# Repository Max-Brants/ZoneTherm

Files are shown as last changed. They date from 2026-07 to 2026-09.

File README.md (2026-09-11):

<picture>
  <source media="(prefers-color-scheme: dark)" srcset="brand/zonetherm-logo-dark.svg">
  ZoneTherm
</picture>

# ZoneTherm

**A 7-zone OpenTherm heating/cooling controller.** ESP32-S3 firmware, KiCad
hardware, and a Svelte web UI for a house where every room has its own
OpenTherm room thermostat but the plant has a single manifold of zone valves.

Version 1.0.0.

---

## The idea

A normal OpenTherm setup is one thermostat talking to one boiler. ZoneTherm sits
in the middle of seven of those conversations at once:

```
 Room thermostat 1  ──OpenTherm──┐
 Room thermostat 2  ──OpenTherm──┤
        ...                      ├──►  ZoneTherm  ──I²C──►  MCP23017  ──►  7 zone valves
 Room thermostat 7  ──OpenTherm──┘        │
                                          ├──► Ethernet / WiFi ──► MQTT ──► Home Assistant
                                          └──► Web UI + REST API
```

To each thermostat, ZoneTherm **pretends to be a boiler**. It answers every
OpenTherm request the thermostat makes, so the thermostat behaves exactly as it
would on a real appliance — it shows a flame, it runs its own schedule, it lets
you turn the dial. While answering, ZoneTherm captures the two numbers that
matter: the room temperature the thermostat measured, and the setpoint it is
asking for.

It then makes the only decision that is actually its own: for each thermostat,
should heat be flowing? That is a bang-bang comparison with a symmetric
hysteresis band, and it lives in exactly one function
([`ClimateLogic::valveWanted`](Code/src/domain/ClimateLogic.h)).

Each thermostat drives a **valve set** — one valve, or several. A room with
three underfloor loops has three actuators and one thermostat, and they open
and close together in a single I²C write.
[`ValvePlan::solve`](Code/src/domain/ValvePlan.h) turns the seven per-room
answers into the one byte the expander wants. A valve belongs to at most one
thermostat, which the web UI enforces by greying out valves already taken and
the API enforces by rejecting the save.

One **season** — heating or cooling — applies to the whole plant, because
there is one set of pipes. Individual zones can be disabled, but they cannot
disagree about which direction the water is going.

Setpoints can also be pushed the other way. A setpoint sent from Home Assistant
or the web UI is written back to the room thermostat over OpenTherm's
`TrOverride` mechanism, so the wall unit shows the new target too.

### Things worth knowing before you build one

- ZoneTherm **is not a gateway.** There is no upstream boiler connection in the
  main firmware. It terminates all seven OpenTherm links itself and drives
  valves; your boiler is expected to be commanded by something else (a valve
  end-switch loop, or its own thermostat input).
- A zone whose thermostat has never reported a room temperature keeps its valves
  **closed**, as does a disabled zone. There is no fail-open.
- The same goes for the two ways a valve set can be misconfigured: a thermostat
  with **no valves** keeps tracking its band and reporting demand but opens
  nothing, and a valve **claimed by nobody** never opens. Both are flagged on
  the config page and logged at boot rather than silently guessed at.
- Upgrading from a pre-valve-set firmware leaves the wiring alone: every
  thermostat comes up owning the one valve on its own channel, exactly as
  before.
- `boilerTemp`, `flameOn`, `fault` and friends exist in the zone state and are
  parsed off the wire, but only `modulation` is currently exported as a Home
  Assistant sensor.

---

## Repository layout

| Path | What it is |
|---|---|
| [Code/](Code/) | ESP32-S3 firmware (ESP-IDF via PlatformIO). See [Code/README.md](Code/README.md) for the architecture write-up. |
| [Code/webui/](Code/webui/) | Svelte 5 + Vite + TypeScript single-page app, built into `Code/data/` and flashed as a LittleFS image. |
| [pcb/](pcb/) | KiCad 8 project `ZoneTherm.kicad_pro` — seven OpenTherm slave interfaces, W5500 Ethernet, MCP23017 valve bank. Fabrication outputs in `GERBER/`, `production/`, `jlcpcb/`. |
| [enclosure/](enclosure/) | Three-part printed case, generated from the KiCad board by a script rather than measured off it. See [enclosure/README.md](enclosure/README.md) — **read the mains section before printing one**. |
| [.github/workflows/](.github/workflows/) | Release workflow that builds and publishes the OTA assets. |

---

## Hardware

**Board:** ESP32-S3-DevKitC-1 (16 MB flash, no PSRAM required).

**Pinout** — from [`Code/src/app/Pins.h`](Code/src/app/Pins.h), matching the
`Thermos_In_X` / `Thermos_Out_X` nets on the schematic:

| Zone | In (GPIO) | Out (GPIO) |
|---|---|---|
| 1 | 2 | 1 |
| 2 | 42 | 41 |
| 3 | 40 | 39 |
| 4 | 48 | 47 |
| 5 | 20 | 19 |
| 6 | 18 | 17 |
| 7 | 16 | 15 |

I²C to the MCP23017 valve expander: `SDA = 4`, `SCL = 5`.
Ethernet is a W5500 on SPI — see U3 on `ZoneTherm.kicad_pcb`.

**Flash layout** ([`Code/partitions.csv`](Code/partitions.csv)) — dual OTA app
slots plus a large filesystem, which is what makes both firmware *and* web UI
updatable over the air:

| Partition | Offset | Size |
|---|---|---|
| `nvs` | 0x9000 | 16 KB |
| `otadata` | 0xd000 | 8 KB |
| `ota_0` | 0x10000 | 3 MB |
| `ota_1` | 0x310000 | 3 MB |
| `littlefs` | 0x610000 | ~10 MB |

---

## Getting started

### 1. Build and flash

PlatformIO is the primary path. On Windows, `pio` may not be on `PATH` —
`~/.platformio/penv/Scripts/platformio.exe` is the full path.

```bash
cd Code
pio run                 # build firmware
pio run -t upload       # flash over USB
pio run -t buildfs      # build the web UI into data/ and pack a LittleFS image
pio run -t uploadfs     # flash the filesystem
pio run -t monitor      # serial console @ 115200
```

`buildfs`/`uploadfs` run [`webui_build.py`](Code/webui_build.py) first, so the
image always contains the current `webui/src` rather than a stale `data/`.

Raw ESP-IDF (`idf.py build`) also works.

**Flash both** the firmware and the filesystem on a new board. Firmware alone
boots but serves no web UI.

### 2. First boot

Network bring-up is automatic and layered:

1. **Ethernet** (DHCP, zero configuration) is tried first and always wins — if
   the link comes up at any later point, WiFi is shut down and Ethernet takes
   over.
2. No Ethernet link → joins the configured **WiFi** as a station.
3. No WiFi configured, or it never gets an IP within 60 s → opens an open
   provisioning access point **`ZoneTherm-<ID>`** at <http://192.168.4.1/>.

`<ID>` is the last three bytes of the MAC in hex, so each controller is
distinct on a shared network.

The device also advertises itself over mDNS as `zonetherm-<ID>.local`.

### 3. Configure

Everything is runtime-configurable — **no credentials live in the source
tree**. Open `http://<device>/config` (or `POST /api/config`) and set:

- hostname
- WiFi SSID / password
- MQTT broker host, port, username, password, base topic, discovery prefix
- season (heating / cooling)
- valve hysteresis
- per-zone name, enabled flag, and valve set
- update repo, check interval, auto-install, include-filesystem

Settings persist in NVS namespace `otcfg`. `POST /api/factory-reset` erases it.

---

## Web UI and REST API

The SPA is served from LittleFS at `/` (zones), `/diagnostics` (thermostat
links and controller state; `/thermostats` is the old name and still works),
`/config` (settings) and `/update`. `/restart` and a 404 page are standalone
HTML so they still render while the device is rebooting or when assets are
missing. The visual identity is documented in [brand/](brand/).

| Endpoint | Method | Purpose |
|---|---|---|
| `/api/system` | GET | hostname, ip, mac, network, heap, uptime, cpuFreq, flashSize, sdkVersion, fwVersion, mode |
| `/api/thermostats` | GET | all seven zones (see below) |
| `/api/config` | GET / POST | full runtime config; secrets are masked on read |
| `/api/system/mode` | POST | set the plant season |
| `/api/thermostat/<1-7>/settemp` | POST | `temp=` — pushes a setpoint to the thermostat via TrOverride |
| `/api/thermostat/<1-7>/setname` | POST | `name=` — 1–32 characters |
| `/api/thermostat/<1-7>/enable` | POST | `enabled=true\|false` |
| `/api/factory-reset` | POST | wipe NVS |
| `/api/update` | GET | updater status |
| `/api/update/check` | POST | check GitHub for a newer release now |
| `/api/update/install` | POST | install the discovered release |
| `/ota/start`, `/update` | GET / POST | manual firmware/filesystem image upload |

Each zone in `/api/thermostats` carries: `id`, `name`, `enabled`, `status`
(`Active`/`Inactive`), `currentTemp`, `setpoint`, `modulation`,
`valves`, `valveOpen`, `action`, `errorCode`, `totalRequests`, `failedRequests`.

`valves` is the set this thermostat drives, as 1-based valve numbers —
`"valves": [1, 2, 3]` for a room with three loops. `valveOpen` means *at least
one of them is open*, so it is false for a thermostat that owns none. The same
array is read and written by `/api/config`; a `POST` that gives one valve to two
thermostats is rejected with `400` and changes nothing:

```bash
curl -X POST http://zonetherm.local/api/config -H 'Content-Type: application/json' \
  -d '{"zones":[{"id":1,"valves":[1,2,3]},{"id":2,"valves":[4,5]}]}'
```

---

## MQTT and Home Assistant

Set a broker on `/config` and ZoneTherm publishes **Home Assistant MQTT
auto-discovery** itself — no YAML. You get one `climate` entity plus a
modulation sensor per zone.

Base topic defaults to `zonetherm/<ID>` and is configurable. Per zone `N`
(1–7):

**Published state**

| Topic | Payload |
|---|---|
| `thermostat/N/temperature` | current room temperature |
| `thermostat/N/setpoint/state` | active setpoint |
| `thermostat/N/mode/state` | `off` \| `heat` \| `cool` |
| `thermostat/N/action` | `off` \| `idle` \| `heating` \| `cooling` |
| `thermostat/N/modulation` | % |
| `thermostat/N/state` | JSON attributes blob |

**Subscribed commands**

| Topic | Payload |
|---|---|
| `thermostat/N/setpoint/command` | target temperature |
| `thermostat/N/mode/command` | `off` disables the zone; `heat`/`cool` enables it |
| `system/mode/command` | `heating` \| `cooling` |

**Plant-wide:** `system/mode/state` and `status` are retained; `status` is also
the last-will topic, so an unplugged controller shows as unavailable in Home
Assistant rather than silently freezing at its last values.

Zone state is republished every 30 s, and immediately on a change.

A zone's HA climate mode maps onto the zone's enabled flag: `off` = disabled,
`heat`/`cool` = enabled under the current season. You cannot put one zone into
cooling while the rest heat — that is a plant-level setting.

---

## Over-the-air updates

ZoneTherm can pull its own releases from GitHub. Configure the repo
(`owner/name`) and interval on `/config`; the default is a 24 h check with
**notify-only** behaviour, so nothing installs without a click unless you
enable auto-install.

Version discovery deliberately **avoids the GitHub REST API**: this board has
no PSRAM, and a `/releases/latest` JSON body would have to be buffered and
parsed on a heap already shared with the HTTP server, MQTT and the OpenTherm
engine. Instead the updater requests `https://github.com/<repo>/releases/latest`
with redirects disabled and reads the tag out of the 302 `Location` header —
one request, zero body bytes, no rate limit, and it works for hand-made
releases. Assets then live at predictable
`.../releases/download/<tag>/{firmware.bin,littlefs.bin}` URLs.

Pushing a `v*` tag runs [`release.yml`](.github/workflows/release.yml), which
stamps the tag into `Version.h`, builds both images, trims the ~10 MB of erased
padding off `littlefs.bin`, and publishes them with a `SHA256SUMS.txt`.

Two constraints worth knowing:

- **The device only installs a strictly newer semver.** With 1.0.0 flashed, tag
  `v1.0.1` to actually exercise the updater.
- **Rollback needs one serial flash to arm.** `CONFIG_BOOTLOADER_APP_ROLLBACK_ENABLE`
  is set, and an OTA image boots on probation — `UpdateService` only confirms it
  once the network is up, so a release that cannot get online reverts instead of
  stranding the controller. But the revert logic lives in the *bootloader*, which
  cannot be delivered over the air. Devices flashed before this option was added
  keep the old bootloader until reflashed over USB.
- Asset filenames are hard-coded device-side. Renaming one silently breaks every
  deployed controller.

---

## Architecture at a glance

Full write-up in [Code/README.md](Code/README.md). The short version:

- `Main.cpp` is the composition root — every object is built there and wired by
  reference. No singletons.
- `domain/` is pure logic with no ESP-IDF includes — the frame codec, the request
  responder, the zone registry, the per-room valve decision and the valve-set
  aggregation — so it can be compiled off-device.
- A dedicated `ot_task` (core 1, priority 15) owns all OpenTherm I/O. Responses
  are transmitted 40 ms after the request **by deadline** rather than by
  sleeping, so one channel cannot stall the other six.
- The main task ticks network, valves, MQTT and the updater at 1 Hz.
- All shared zone state lives in `ZoneRegistry` behind a single mutex; callers
  only ever receive value snapshots, never references into locked state.

---

## Credits and licensing

ZoneTherm is released under the MIT License — see [LICENSE](LICENSE).

Third-party code lives in `Code/src/vendor/`. Both libraries keep their upstream
register maps, frame logic and public APIs; only the hardware touchpoints were
rewritten for native ESP-IDF:

- **OpenTherm library** — [ihormelnyk/OpenTherm](https://github.com/ihormelnyk/OpenTherm),
  MIT, © 2023 Ihor Melnyk. Ported from Arduino to native ESP-IDF GPIO/timer APIs.
- **MCP23017 driver** — [blemasle/arduino-mcp23017](https://github.com/blemasle/arduino-mcp23017),
  MIT, © 2017 Bertrand Lemasle. Ported from Arduino `Wire` to `driver/i2c_master.h`.

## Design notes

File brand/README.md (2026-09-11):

# ZoneTherm brand

The identity for the controller, its web interface, and anything printed
about it. The web UI implements these rules in `Code/webui/src/style.css` and
`Code/webui/src/components/Brand.svelte`; the assets here are the source for
everything else.

## The mark

ZoneTherm mark

A **Z drawn as a single pipe run**. The top bar is the supply, the diagonal is
the flow, the bottom bar is the return. The stroke runs from ember at the top to
glacier at the bottom: one plant, two seasons. It sits on an ink tile with a
corner radius of a quarter of the side, so it reads at a 16 px favicon as well
as on a 100 mm enclosure lid.

| File | Use |
|---|---|
| `zonetherm-mark.svg` | The tile mark. Favicons, app icons, avatars, the enclosure. |
| `zonetherm-mark-mono.svg` | The Z alone, one colour. Silkscreen, engraving, one-colour print. |
| `zonetherm-logo.svg` | Horizontal lockup for light backgrounds. README, documentation. |
| `zonetherm-logo-dark.svg` | The same lockup for dark backgrounds. |

Geometry, in the 32-unit tile: the Z spans x 10 to 22 and y 9.5 to 22.5, stroke
width 4.25, round caps and joins. Do not restyle the stroke, add a third colour,
or set the tile on a gradient.

## Wordmark

*ZoneTherm*, one word, capital Z and capital T. Set in Inter (or the system UI
face when Inter is unavailable), semibold, tracked -0.02 em. In running text it
is plain: ZoneTherm. Lowercase `zonetherm` is reserved for hostnames, MQTT
topics and package names.

## Colour

Colour means something or it is not used. The interface is ink on warm-neutral
paper; the three chromatic colours each carry exactly one meaning.

| Token | Light | Dark | Meaning |
|---|---|---|---|
| Paper | `#F2F2EF` | `#131311` | Page background |
| Surface | `#FFFFFF` | `#1B1B18` | Cards, inputs, tables |
| Ink | `#1C1C19` | `#ECEBE6` | Text, every control, the active state |
| Ember | `#CF4A1C` | `#F26A3D` | A zone that is heating right now. Nothing else. |
| Glacier | `#2477B8` | `#5AAEE6` | A zone that is cooling right now. Nothing else. |
| Amber | `#A86500` | `#E0A232` | A thermostat with no signal, a valve nobody owns |
| Signal red | `#B3261E` | `#EF5350` | Errors and destructive actions |

The mark uses slightly brighter ember (`#F0673D`) and glacier (`#4FA8E3`)
because it sits on ink.

## Type

One family, system-served: Inter, then the platform UI face. Five sizes in the
interface: 12, 13, 14 (body), 16 (section titles), 22 (page titles), plus the
44 px room temperature, which is the only large type on any screen. Numbers
that stack use tabular figures. Sentence case everywhere; no all-caps labels.

## Voice

Every page opens with one plain sentence that says what the page currently
shows: "2 of 7 rooms are calling for heat." Copy is specific to the plant
(rooms, valves, thermostats, seasons), never generic ("overview", "dashboard").
No exclamation marks.

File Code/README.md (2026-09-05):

# ZoneTherm firmware

Architecture notes for the firmware. For the project overview, hardware,
wiring, API and Home Assistant surface, see the [root README](../README.md).

ESP32-S3 firmware that emulates an OpenTherm **boiler** on 7 channels. Each
channel has a real room thermostat (OpenTherm master) plugged in; the
controller answers its requests, captures the room temperature and setpoint
it reports, and drives that thermostat's valve set through an MCP23017 I2C
expander. A thermostat can own several valves (a room with three underfloor
loops) or none, and a valve belongs to at most one thermostat.
One global season (heating/cooling) applies to all zones.

Integrations: MQTT with Home Assistant auto-discovery (one climate + two
sensors per zone), a LittleFS-served web UI with REST API, dual-image OTA
(firmware and filesystem), mDNS, SNTP.

## Building

PlatformIO (primary): `pio run`, web assets: `pio run -t buildfs`, flash
with `pio run -t upload` / `-t uploadfs`. Raw ESP-IDF (`idf.py build`) works
too.

## Testing

`pio test -e native` runs the host unit tests. The `native` env is plain g++
against libstdc++ - no board, no framework, no IDF - and `build_src_filter`
limits it to `src/domain/`, which is the tested boundary. Suites live in
`test/`:

| Suite | Covers |
|---|---|
| `test_ot_frame` | frame codec: parity, field extraction, f8.8 fixed point |
| `test_ot_responder` | every data ID the slave answers, and its state delta |
| `test_climate_logic` | hysteresis band, both seasons, the fail-safe paths |
| `test_zone_registry` | sparse-delta merge, dirty mask, setpoint clamp |
| `test_string_utils` | urlDecode/trim/parsing on the HTTP request path |
| `test_valve_plan` | valve-set aggregation, the demand latch, exclusivity, unassigned valves |

CI is where these normally run - `.github/workflows/ci.yml` runs them plus a
full firmware build on every push and PR, and `release.yml` runs them before
publishing OTA assets.

Running them locally needs `gcc`/`g++` on `PATH`. PlatformIO's `native`
platform shells out to those names specifically, so an MSVC install does not
satisfy it - on a stock Windows box every suite ERRORs with `'g++' is not
recognized` before compiling anything. Install MSYS2/MinGW to run them here,
or just let CI do it.

A few tests assert behavior worth questioning rather than behavior worth
keeping - the staleness hold in `test_climate_logic` and the 0 degC sentinel
in `test_ot_responder`. Each is flagged with a comment saying so.

## Source layout

`Main.cpp` is the composition root - it builds every object and wires them
by reference; there are no singletons.

```
src/
  app/        Version.h, Pins.h (board wiring)
  domain/     pure logic, no ESP-IDF includes, compiles off-device:
              OtFrame (frame codec), OtResponder (request -> response +
              state delta), ZoneRegistry (all zone state behind one lock),
              ClimateLogic (the per-room decision, with hysteresis),
              ValvePlan (valve sets -> the open-valve mask, plus the
              exclusivity rules the API enforces)
  drivers/    OtChannel (vendored OpenTherm wrapper), ValveBank (MCP23017)
  services/   ConfigStore (NVS), OtEngine (OT task, deadline-scheduled
              responses), ControlService (1 Hz valve tick), MqttService,
              HaDiscovery, TimeService, ZoneJson (the one zone serializer)
  net/        NetworkManager (state machine), EthDriver (W5500),
              WifiDriver (STA + provisioning AP), MdnsService
  web/        HttpServer (pages), ApiRoutes (REST), OtaRoutes (fw+fs OTA)
  vendor/     unmodified third-party: OpenTherm, MCP23017
```

Concurrency: a dedicated `ot_task` (core 1, prio 15) owns all OpenTherm
I/O; responses are transmitted 40 ms after the request by deadline instead
of sleeping. The main task ticks network/valves/MQTT at 1 Hz. esp-mqtt and
esp_http_server run their own tasks. All shared zone state lives in
`ZoneRegistry` behind one mutex; callers only ever get value snapshots.

## Configuration

Everything is runtime-configurable at **http://\<device\>/config** (or
`GET/POST /api/config`) and stored in NVS namespace `otcfg`: hostname, WiFi
credentials, MQTT broker/credentials/topics, season, valve hysteresis, and
per-zone name + enabled flag + valve set. No credentials live in the source
tree.

Valve sets are stored one byte per zone under `z<i>_vlv` (bit v = valve v,
V1 = bit 0). Stores written before schema v3 have no such key, and `readNvs()`
only overwrites keys that exist, so an upgraded device keeps the 1:1 mapping
`applyDefaults()` installs — zone *i* drives valve *i*, exactly as before.

Network bring-up: Ethernet (DHCP, zero config) is primary. Without a link,
the device joins the configured WiFi as a station; with no WiFi configured
(or when it never connects), it opens the open provisioning AP
`ZoneTherm-<ID>` at http://192.168.4.1/ where the config page is served.
Ethernet coming up at any point always wins.

Devices already provisioned keep their stored hostname and MQTT base topic;
only fresh or factory-reset devices pick up the `zonetherm-<ID>` /
`zonetherm/<ID>` defaults.

## MQTT surface

Base topic default `zonetherm/<ID>` (configurable). Per zone `N` (1-7):
state topics `thermostat/N/{temperature, setpoint/state, mode/state,
action, modulation, state}` and commands
`thermostat/N/{setpoint, mode}/command`. Zone state is republished every
30 s and on change. Plant-wide: `system/mode/{state,command}` (`heating`/`cooling`)
and retained availability on `status` (with LWT). A zone's HA climate mode
maps `off` = zone disabled, `heat`/`cool` = enabled under the current
season. Setpoint commands are pushed to the room thermostat via the
OpenTherm TrOverride mechanism.

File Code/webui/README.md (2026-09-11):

# ZoneTherm Web UI

Svelte 5 + Vite + TypeScript single-page app for the controller's web interface.
API payload types (mirroring `src/web/ApiRoutes.cpp`) live in `src/lib/types.ts`.
Run `npm run check` (svelte-check) to type-check.

## Pages

| Route | Page | What it is for |
|---|---|---|
| `/` | Zones | The control surface: every room's temperature, setpoint and whether it is heating, plus the plant season. |
| `/diagnostics` (also `/thermostats`) | Diagnostics | OpenTherm link health per channel, valve state, and the controller's network and memory figures. Restart lives here. |
| `/config` | Settings | Everything stored in NVS, with a save bar that appears only when something changed. |
| `/update` | Update | GitHub release status and the manual image upload. |

`restart.html` and `404.html` are standalone pages in `public/`; they load only
`style.css` and must not depend on the SPA, because they are shown while the
device reboots or when assets are missing.

## Design

Warm-neutral paper, ink for every control, and colour only where it carries
meaning: ember for a zone that is heating, glacier blue for one that is cooling,
amber for a thermostat with no signal. Tokens are at the top of `src/style.css`;
the mark and wordmark are `src/components/Brand.svelte`, mirrored by
`public/favicon.svg` and the assets in `../../brand/`. System fonts only, since
the device serves everything itself from LittleFS.

## Build

```
npm install
npm run build
```

The build writes straight into `../data/` (the LittleFS image source):

- `index.html`, `app.js`, `style.css` — the SPA, served for `/`, `/diagnostics`, `/thermostats`, `/config`, `/update`
- `restart.html`, `404.html`, `favicon.svg` — copied from `public/`

Filenames are fixed (no content hashes) because the firmware registers explicit
routes for `/app.js`, `/style.css` and `/favicon.svg` (see `src/web/HttpServer.cpp`).

After building, flash the filesystem image (PlatformIO "Upload Filesystem Image",
or the web updater in Filesystem mode with a built LittleFS .bin).

## Development

Against a real controller:

```
npm run dev
```

Vite serves the app locally and proxies `/api`, `/ota`, `/update`, `/restart` to a
running controller (`http://zonetherm.local` by default; override with the
`VITE_DEVICE` environment variable).

Without hardware, run the in-memory mock controller in one terminal and point
Vite at it in another:

```
npm run mock
npm run dev:mock
```

`mock/server.mjs` answers every endpoint the UI uses, drifts room temperatures
towards their setpoints, and walks the updater through a check and an install.

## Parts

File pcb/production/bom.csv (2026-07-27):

Designator | Footprint | Quantity | Value | LCSC Part #
C1, C18, C19, C20, C21, C22 | 0402 | 6 | 0.1uf
C10 | 0402 | 1 | 0.1uf | C1525
C11 | 0603 | 1 | 150pf | C1594
C12 | 0603 | 1 | 1500pf | C1595
C13 | 1206 | 1 | 100uf | C15008
C14, C7 | 0402 | 2 | 6.8nF
C15 | 0805 | 1 | 10uf
C17 | 0402 | 1 | 1uf
C26, C27 | 0402 | 2 | 18pf
C3 | CP_Elec_8x10.5 | 1 | 330 uf
C6 | 0603 | 1 | 0.1uf | C14663
C8 | 0402 | 1 | 0.01uf | C15195
C9 | 1206 | 1 | 4.7uf | C29823
D1, D14, D2, D3, D4, D5, D6, D7 | 0805 | 8 | LED | C2297
D10, D15, D16, D17 | D_SOD-323 | 4 | 1N4148WS | C2128
D11 | D_SOD-323_HandSoldering | 1 | 4V7
D12 | D_SOD-323_HandSoldering | 1 | 4V3
D13 | D_SOD-323_HandSoldering | 1 | 13V
D23, D24, D25, D26, D27, D28, D29 | 0805 | 7 | LED | C84256
F1 | Fuseholder_Cylinder-5x20mm_Schurter_0031_8201_Horizontal_Open | 1 | Fuse
J17 | Altech_AK100_1x04_P5.00mm | 1 | Screw_Terminal
J18 | USB_C_Receptacle_Palconn_UTC16-G | 1 | USB_C_Receptacle
J9 | RJ45_Hanrun_HR911105A_Horizontal | 1 | RJ45_Hanrun_HR911105A_Horizontal
L2 | L_Changjiang_FXL0630 | 1 | 15uh/3A | C5189959
L3 | 0603 | 1 | BLM18PG121SN1D | C14709
Q1, Q11, Q12, Q13, Q16, Q17, Q18, Q2, Q21, Q22, Q23, Q26, Q27, Q28, Q3, Q32, Q39, Q40, Q41, Q6, Q7, Q8 | SOT-23 | 22 | BC858B | C8542
Q10, Q14, Q15, Q19, Q20, Q24, Q25, Q29, Q30, Q31, Q33, Q34, Q35, Q36, Q37, Q38, Q4, Q42, Q43, Q5, Q53, Q54, Q9 | SOT-23 | 23 | BC848C | C2146
Q46, Q47, Q48, Q49, Q50, Q51, Q52 | SOT-223-3_TabPin2 | 7 | BT134W | C2831689
R1, R16, R25, R33, R41, R68, R9 | 0603 | 7 | 33k | C4216
R10, R17, R2, R26, R34, R42, R54, R69 | 0603 | 8 | 100 | C22775
R100, R101, R102, R103, R104, R105, R52, R85, R99 | 0603 | 9 | 330 | C23138
R106, R107, R108, R109, R110, R111, R112, R23, R24, R32, R40, R48, R75, R8 | 0603 | 14 | 51 | C23197
R11, R18, R27, R3, R35, R43, R70 | 0603 | 7 | 33 | C23140
R113, R114, R115, R116, R117, R97, R98 | 0805 | 7 | 330
R118, R119, R120, R121, R123, R124 | 0402 | 6 | 49R9
R12, R19, R28, R36, R4, R44, R71 | 0603 | 7 | 20k | C4184
R122 | 0402 | 1 | 10R
R125 | 0402 | 1 | 12.4K
R13, R20, R29, R37, R45, R5, R50, R58, R59, R61, R63, R65, R67, R72, R90, R91, R92, R93, R94, R95 | 0603 | 20 | 10k | C25804
R14, R21, R30, R38, R46, R49, R51, R56, R57, R6, R60, R62, R64, R66, R73 | 0603 | 15 | 1k | C21190
R15, R22, R31, R39, R47, R7, R74, R83, R84 | 0603 | 9 | 4k7 | C23162
R53 | 0603 | 1 | 220 | C22962
R55 | 0603 | 1 | 1.5k | C22843
R86, R87 | 0402 | 2 | 5.1K | C25905
R88 | 0603 | 1 | 549 | C23204
R89 | 0603 | 1 | 3.9K | C23018
R96 | 0603 | 1 | 2K | C22975
SW1 | SW-SMD_L3.9-W3.0-P4.45 | 1 | Boot | C720477
SW2 | SW-SMD_L3.9-W3.0-P4.45 | 1 | Reset | C720477
U1 | SOIC-16_3.9x9.9mm_P1.27mm | 1 | CH340C | C84681
U10, U11, U12, U13, U7, U8, U9 | SMDIP-6_W9.53mm | 7 | MOC3023S-TA1 | C115469
U3 | LQFP-48_7x7mm_P0.5mm | 1 | W5500 | C32843
U6 | TI_SO-PowerPAD-8 | 1 | TPS5430DDA | C9864

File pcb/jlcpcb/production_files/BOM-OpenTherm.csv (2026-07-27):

Comment | Designator | Footprint | LCSC | Quantity
0.01uf | C8 | C_0402_1005Metric | C15195 | 1
0.1uf | C18,C19,C20,C21,C22 | C_0402_1005Metric | C141382 | 5
0.1uf | C6 | C_0603_1608Metric | C14663 | 1
0.1uf | C10 | C_0402_1005Metric | C1525 | 1
0.1uf | C1 | C_0402_1005Metric | C307331 | 1
1.5k | R55 | R_0603_1608Metric | C22843 | 1
100 | R10,R17,R2,R26,R34,R42,R54,R69 | R_0603_1608Metric | C22775 | 8
100uf | C13 | C_1206_3216Metric | C15008 | 1
10K | R90,R91,R92,R95 | R_0603_1608Metric | C25804 | 4
10R | R122 | R_0402_1005Metric | C25077 | 1
10k | R13,R20,R29,R37,R45,R5,R50,R58,R59,R61,R63,R65,R67,R72,R93,R94 | R_0603_1608Metric | C25804 | 16
10nf | C15,C17,C24 | C_0402_1005Metric | C15195 | 3
10uf/16v | C23 | CP_EIA-3216-18_Kemet-A | C7171 | 1
12.4K | R125 | R_0402_1005Metric | C11692 | 1
1500pf | C12 | C_0603_1608Metric | C1595 | 1
150pf | C11 | C_0603_1608Metric | C1594 | 1
15uh/3A | L2 | L_Changjiang_FXL0630 | C5189959 | 1
18pf | C26,C27 | C_0402_1005Metric | C1549 | 2
1M | R126 | R_0402_1005Metric | C26083 | 1
1N4148WS | D10,D15,D16,D17,D18,D19,D20,D21,D22,D8,D9 | D_SOD-323 | C2128 | 11
1k | R14,R21,R30,R38,R46,R49,R51,R56,R57,R6,R60,R62,R64,R66,R73 | R_0603_1608Metric | C21190 | 15
1uf | C5 | C_0603_1608Metric | C15849 | 1
20k | R12,R19,R28,R36,R4,R44,R71 | R_0603_1608Metric | C4184 | 7
220 | R53 | R_0603_1608Metric | C22962 | 1
22nf | C16 | C_0402_1005Metric | C1532 | 1
22uf | C2 | C_0603_1608Metric | C59461 | 1
25MH | Y1 | Crystal_SMD_TXC_7M-4Pin_3.2x2.5mm | C9006 | 1
2K | R96 | R_0603_1608Metric | C22975 | 1
3.9K | R89 | R_0603_1608Metric | C23018 | 1
33 | R11,R18,R27,R3,R35,R43,R70 | R_0603_1608Metric | C23140 | 7
330 | R52,R85 | R_0603_1608Metric | C23138 | 2
330 | R123,R124 | R_0402_1005Metric | C25104 | 2
33k | R1,R16,R25,R33,R41,R68,R9 | R_0603_1608Metric | C4216 | 7
4.7uf | C25 | C_0402_1005Metric | C23733 | 1
4.7uf | C9 | C_1206_3216Metric | C29823 | 1
49R9 | R118,R119,R120,R121 | R_0402_1005Metric | C25120 | 4
4k7 | R15,R22,R31,R39,R47,R7,R74,R83,R84 | R_0603_1608Metric | C23162 | 9
5.1K | R86,R87 | R_0402_1005Metric | C25905 | 2
51 | R23,R24,R32,R40,R48,R75,R8 | R_0603_1608Metric | C23197 | 7
549 | R88 | R_0603_1608Metric | C23204 | 1
6.8nF | C14,C7 | C_0402_1005Metric | C1542 | 2
BC848C | Q10,Q14,Q15,Q19,Q20,Q24,Q25,Q29,Q30,Q31,Q33,Q34,Q35,Q36,Q37,Q38,Q4,Q42,Q43,Q5,Q53,Q54,Q9 | SOT-23 | C2146 | 23
BC858B | Q1,Q11,Q12,Q13,Q16,Q17,Q18,Q2,Q21,Q22,Q23,Q26,Q27,Q28,Q3,Q32,Q39,Q40,Q41,Q6,Q7,Q8 | SOT-23 | C8542 | 22
BLM18PG121SN1D | L3 | L_0603_1608Metric | C14709 | 1
Boot | SW1 | SW-SMD_L3.9-W3.0-P4.45 | C720477 | 1
CH340C | U1 | SOIC-16_3.9x9.9mm_P1.27mm | C84681 | 1
G5NB-1A-E-24VDC | J19,J20,J21,J22,J23,J25,J26 | RELAY-TH_G5NB-1A-E-24VDC | C34758 | 7
LED | D1,D14,D2,D3,D4,D5,D6,D7 | LED_0805_2012Metric | C2297 | 8
MRBS340 | D32 | D_SMC | C16237 | 1
RJ45_Hanrun_HR911105A_Horizontal | J9 | RJ45_Hanrun_HR911105A_Horizontal | C12074 | 1
Reset | SW2 | SW-SMD_L3.9-W3.0-P4.45 | C720477 | 1
TPS5430DDA | U6 | TI_SO-PowerPAD-8 | C9864 | 1
USB_C_Receptacle | J18 | USB_C_Receptacle_Palconn_UTC16-G | C2765186 | 1
W5500 | U3 | LQFP-48_7x7mm_P0.5mm | C32843 | 1
Conn_01x02 | J5 | PhoenixContact_MSTBA_2,5_2-G-5,08_1x02_P5.08mm_Horizontal |  | 1
Conn_01x02 | J2 | PhoenixContact_MSTBA_2,5_2-G-5,08_1x02_P5.08mm_Horizontal |  | 1
Fuse | F1 | Fuseholder_Cylinder-5x20mm_Schurter_0031_8201_Horizontal_Open |  | 1
Conn_01x02 | J8 | PhoenixContact_MSTBA_2,5_2-G-5,08_1x02_P5.08mm_Horizontal |  | 1
Screw_Terminal | J17 | Altech_AK100_1x04_P5.00mm |  | 1
4V3 | D12 | D_SOD-323_HandSoldering |  | 1
Conn_01x04 | J11 | PhoenixContact_MSTBA_2,5_4-G-5,08_1x04_P5.08mm_Horizontal |  | 1
13V | D13 | D_SOD-323_HandSoldering |  | 1
ESP32-S3-WROOM-1 | U4 | ESP32-S3-WROOM-1 |  | 1
Conn_01x06 | J10 | PhoenixContact_MSTBA_2,5_6-G-5,08_1x06_P5.08mm_Horizontal |  | 1
4V7 | D11 | D_SOD-323_HandSoldering |  | 1
PC817XNNIP1B | Q45 | SOP254P960X420-4N |  | 1
Conn_01x02 | J4 | PhoenixContact_MSTBA_2,5_2-G-5,08_1x02_P5.08mm_Horizontal |  | 1
Conn_01x04 | J13 | PhoenixContact_MSTBA_2,5_4-G-5,08_1x04_P5.08mm_Horizontal |  | 1
MCP23017_SO | U2 | SOIC-28W_7.5x17.9mm_P1.27mm |  | 1
Conn_01x02 | J3 | PhoenixContact_MSTBA_2,5_2-G-5,08_1x02_P5.08mm_Horizontal |  | 1
Conn_01x04 | J12 | PhoenixContact_MSTBA_2,5_4-G-5,08_1x04_P5.08mm_Horizontal |  | 1
Conn_01x02 | J24 | PhoenixContact_MSTBA_2,5_2-G-5,08_1x02_P5.08mm_Horizontal |  | 1
Conn_01x04 | J14 | PhoenixContact_MSTBA_2,5_4-G-5,08_1x04_P5.08mm_Horizontal |  | 1
Conn_01x02 | J6 | PhoenixContact_MSTBA_2,5_2-G-5,08_1x02_P5.08mm_Horizontal |  | 1
Conn_01x04 | J15 | PhoenixContact_MSTBA_2,5_4-G-5,08_1x04_P5.08mm_Horizontal |  | 1
PC817XNNIP1B | Q44 | SOP254P960X420-4N |  | 1
Conn_01x03 | J7 | PhoenixContact_MSTBA_2,5_3-G-5,08_1x03_P5.08mm_Horizontal |  | 1
Conn_01x02 | J1 | PhoenixContact_MSTBA_2,5_2-G-5,08_1x02_P5.08mm_Horizontal |  | 1
Conn_01x08 | J16 | PhoenixContact_MSTBA_2,5_8-G-5,08_1x08_P5.08mm_Horizontal |  | 1
330 uf | C3 | CP_Elec_8x10.5 |  | 1

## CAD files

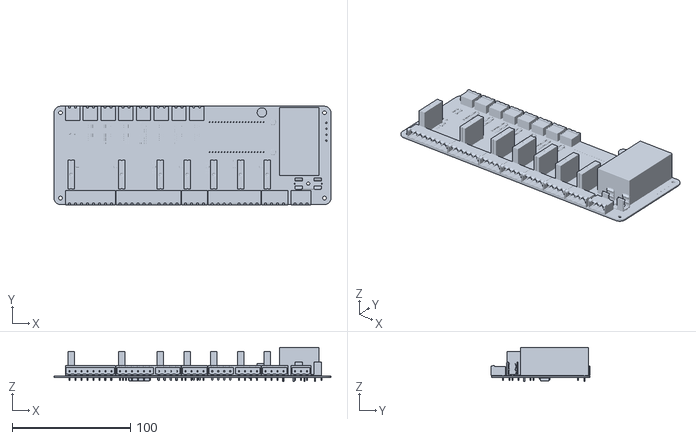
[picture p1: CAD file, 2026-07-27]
pcb/ZoneTherm.stl
234.5 x 83.5 x 28.8

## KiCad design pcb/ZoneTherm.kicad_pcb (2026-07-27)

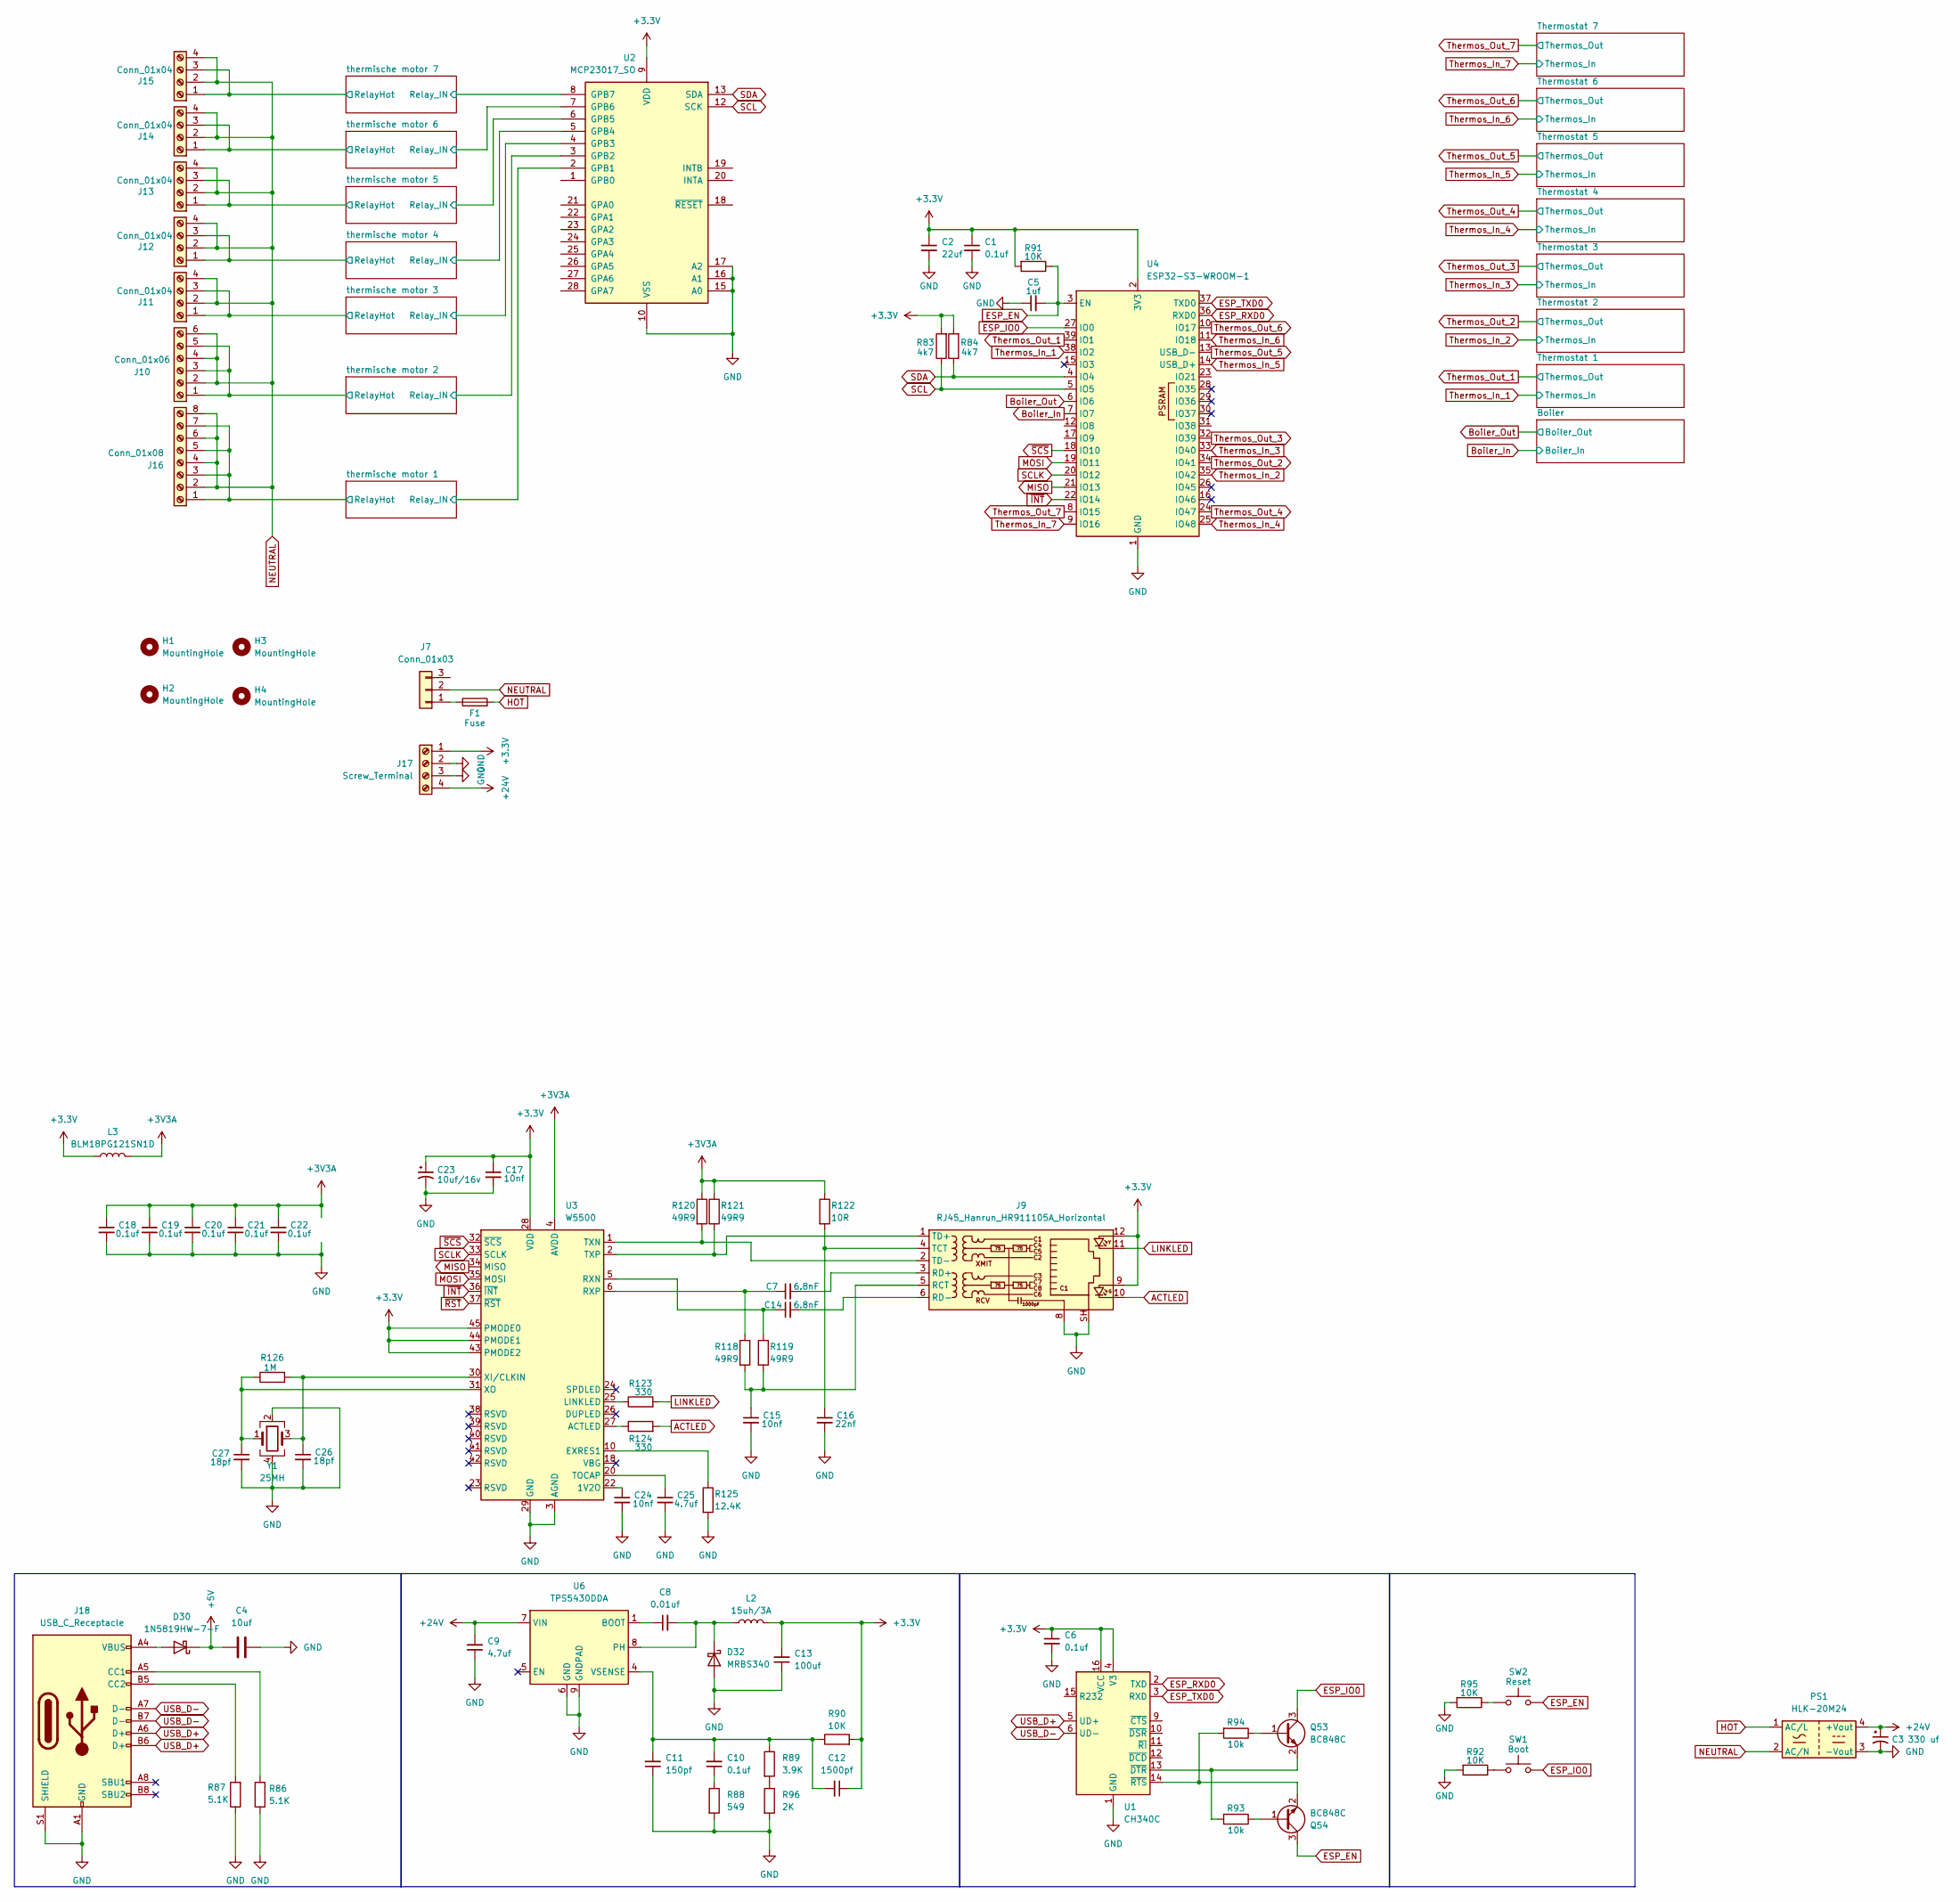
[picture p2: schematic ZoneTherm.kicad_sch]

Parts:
C1, C10, C18, C19, C20, C21, C22: 0.1uf; C_0402_1005Metric
C2: 22uf; C_0603_1608Metric
C3: 330 uf; CP_Elec_8x10.5
C4: 10uf
C5: 1uf; C_0603_1608Metric
C6: 0.1uf; C_0603_1608Metric
C7, C14: 6.8nF; C_0402_1005Metric
C8: 0.01uf; C_0402_1005Metric
C9: 4.7uf; C_1206_3216Metric
C11: 150pf; C_0603_1608Metric
C12: 1500pf; C_0603_1608Metric
C13: 100uf; C_1206_3216Metric
C15, C17, C24: 10nf; C_0402_1005Metric
C16: 22nf; C_0402_1005Metric
C23: 10uf/16v; CP_EIA-3216-18_Kemet-A
C25: 4.7uf; C_0402_1005Metric
C26, C27: 18pf; C_0402_1005Metric
D30: 1N5819HW-7-F
D32: MRBS340; D_SMC
F1: Fuse; Fuseholder_Cylinder-5x20mm_Schurter_0031_8201_Horizontal_Op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
H1, H2, H3, H4: MountingHole; MountingHole_3.2mm_M3
J7: Conn_01x03; PhoenixContact_MSTBA_2,5_3-G-5,08_1x03_P5.08mm_Horizontal
J9: RJ45_Hanrun_HR911105A_Horizontal
J10: Conn_01x06; PhoenixContact_MSTBA_2,5_6-G-5,08_1x06_P5.08mm_Horizontal
J11, J12, J13, J14, J15: Conn_01x04; PhoenixContact_MSTBA_2,5_4-G-5,08_1x04_P5.08mm_Horizontal
J16: Conn_01x08; PhoenixContact_MSTBA_2,5_8-G-5,08_1x08_P5.08mm_Horizontal
J17: Screw_Terminal; Altech_AK100_1x04_P5.00mm
J18: USB_C_Receptacle; USB_C_Receptacle_Palconn_UTC16-G
L2: 15uh/3A; L_Changjiang_FXL0630
L3: BLM18PG121SN1D; L_0603_1608Metric
PS1: HLK-20M24; Converter_ACDC_Hi-Link_HLK-20Mxx
Q53, Q54: BC848C; SOT-23
R83, R84: 4k7; R_0603_1608Metric
R86, R87: 5.1K; R_0402_1005Metric
R88: 549; R_0603_1608Metric
R89: 3.9K; R_0603_1608Metric
R90, R91, R92, R95: 10K; R_0603_1608Metric
R93, R94: 10k; R_0603_1608Metric
R96: 2K; R_0603_1608Metric
R118, R119, R120, R121: 49R9; R_0402_1005Metric
R122: 10R; R_0402_1005Metric
R123, R124: 330; R_0402_1005Metric
R125: 12.4K; R_0402_1005Metric
R126: 1M; R_0402_1005Metric
SW1: Boot; SW-SMD_L3.9-W3.0-P4.45
SW2: Reset; SW-SMD_L3.9-W3.0-P4.45
U1: CH340C; SOIC-16_3.9x9.9mm_P1.27mm
U2: MCP23017_SO; SOIC-28W_7.5x17.9mm_P1.27mm
U3: W5500; LQFP-48_7x7mm_P0.5mm
U4: ESP32-S3-WROOM-1
U6: TPS5430DDA; TI_SO-PowerPAD-8
Y1: 25MH; Crystal_SMD_TXC_7M-4Pin_3.2x2.5mm

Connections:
+3.3V: C1.1, C2.1, C6.1, C12.1, C13.2, C17.1, C23.1, J9.9, J9.12, J17.1, L2.2, L3.1, R83.2, R84.2, R90.2, R91.2, U1.4 (V3), U1.16 (VCC), U2.9 (VDD), U3.28 (VDD), U3.43 (PMODE2), U3.44 (PMODE1), U3.45 (PMODE0), U4.2 (3V3); also elsewhere on the board
+3V3A: C18.1, C19.1, C20.1, C21.1, C22.1, L3.2, R120.1, R121.1, R122.1, U3.4 (AVDD), U3.8 (AVDD), U3.11 (AVDD), U3.15 (AVDD), U3.17 (AVDD), U3.21 (AVDD)
+24V: C3.1, C9.2, J17.4, PS1.4 (+Vout), U6.7 (VIN); also elsewhere on the board
/thermische motor 1/RelayHot: J16.1, J16.3, J16.5, J16.7; also elsewhere on the board
/thermische motor 1/Relay_IN: U2.2 (GPB1); also elsewhere on the board
/thermische motor 2/RelayHot: J10.1, J10.3, J10.5; also elsewhere on the board
/thermische motor 2/Relay_IN: U2.3 (GPB2); also elsewhere on the board
/thermische motor 3/RelayHot: J11.1, J11.3; also elsewhere on the board
/thermische motor 3/Relay_IN: U2.4 (GPB3); also elsewhere on the board
/thermische motor 4/RelayHot: J12.1, J12.3; also elsewhere on the board
/thermische motor 4/Relay_IN: U2.5 (GPB4); also elsewhere on the board
/thermische motor 5/RelayHot: J13.1, J13.3; also elsewhere on the board
/thermische motor 5/Relay_IN: U2.6 (GPB5); also elsewhere on the board
/thermische motor 6/RelayHot: J14.1, J14.3; also elsewhere on the board
/thermische motor 6/Relay_IN: U2.7 (GPB6); also elsewhere on the board
/thermische motor 7/RelayHot: J15.1, J15.3; also elsewhere on the board
/thermische motor 7/Relay_IN: U2.8 (GPB7); also elsewhere on the board
ACTLED: J9.10, R124.2
Boiler_In: U4.7 (IO7); also elsewhere on the board
Boiler_Out: U4.6 (IO6); also elsewhere on the board
ESP_EN: C5.2, Q54.3 (C), R91.1, SW2.2, U4.3 (EN)
ESP_IO0: Q53.3 (C), SW1.2, U4.27 (IO0)
ESP_RXD0: U1.2 (TXD), U4.36 (RXD0)
ESP_TXD0: U1.3 (RXD), U4.37 (TXD0)
GND: C1.2, C2.2, C3.2, C4.1, C5.1, C6.2, C9.1, C11.1, C13.1, C15.2, C16.2, C17.2, C18.2, C19.2, C20.2, C21.2, C22.2, C23.2, C24.2, C25.2, C26.2, C27.2, D32.2 (A), J9.8, J9.SH, J17.2, J17.3, J18.A1 (GND), J18.A12 (GND), J18.B1 (GND), J18.B12 (GND), J18.S1 (SHIELD), PS1.3 (-Vout), R86.1, R87.1, R88.2, R92.2, R95.2, R96.2, R125.2, U1.1 (GND), U2.10 (VSS), U2.15 (A0), U2.16 (A1), U2.17 (A2), U3.3 (AGND), U3.9 (AGND), U3.14 (AGND), U3.16 (AGND), U3.19 (AGND), U3.29 (GND), U3.48 (AGND), U4.1 (GND), U4.40 (GND), U4.41 (GND), U6.6 (GND), U6.9 (GNDPAD), Y1.2, Y1.4; also elsewhere on the board
HOT: F1.2, PS1.1 (AC/L); also elsewhere on the board
LINKLED: J9.11, R123.2
MISO: U3.34 (MISO), U4.21 (IO13)
MOSI: U3.35 (MOSI), U4.19 (IO11)
NEUTRAL: J7.2, J10.2, J10.4, J10.6, J11.2, J11.4, J12.2, J12.4, J13.2, J13.4, J14.2, J14.4, J15.2, J15.4, J16.2, J16.4, J16.6, J16.8, PS1.2 (AC/N)
unnamed: C4.2, D30.1 (K)
unnamed: C10.1, R88.1
unnamed: C8.2, D32.1 (K), L2.1, U6.8 (PH)
unnamed: F1.1, J7.1
unnamed: C15.1, J9.5 (RCT), R118.2, R119.2
unnamed: C7.2, J9.3 (RD+)
unnamed: C14.2, J9.6 (RD-)
unnamed: C16.1, J9.4 (TCT), R122.2
unnamed: J9.1 (TD+), R121.2, U3.2 (TXP)
unnamed: J9.2 (TD-), R120.2, U3.1 (TXN)
unnamed: J18.A5 (CC1), R86.2
unnamed: J18.B5 (CC2), R87.2
unnamed: D30.2 (A), J18.A4 (VBUS), J18.A9 (VBUS), J18.B4 (VBUS), J18.B9 (VBUS)
unnamed: Q53.1 (B), R94.1
unnamed: Q53.2 (E), R93.2, U1.13 (~DTR)
unnamed: Q54.1 (B), R93.1
unnamed: Q54.2 (E), R94.2, U1.14 (~RTS)
unnamed: R89.2, R96.1
unnamed: R92.1, SW1.1
unnamed: R95.1, SW2.1
unnamed: C24.1, U3.22 (1V2O)
unnamed: R124.1, U3.27 (ACTLED)
unnamed: R125.1, U3.10 (EXRES1)
unnamed: R123.1, U3.25 (LINKLED)
unnamed: C14.1, R119.1, U3.5 (RXN)
unnamed: C7.1, R118.1, U3.6 (RXP)
unnamed: C25.1, U3.20 (TOCAP)
unnamed: C26.1, R126.2, U3.30 (XI/CLKIN), Y1.3
unnamed: C27.1, R126.1, U3.31 (XO), Y1.1
unnamed: C8.1, U6.1 (BOOT)
unnamed: C10.2, C11.2, C12.2, R89.1, R90.1, U6.4 (VSENSE)
SCL: R83.1, U2.12 (SCK), U4.5 (IO5)
SCLK: U3.33 (SCLK), U4.20 (IO12)
SDA: R84.1, U2.13 (SDA), U4.4 (IO4)
Thermos_In_1: U4.38 (IO2); also elsewhere on the board
Thermos_In_2: U4.35 (IO42); also elsewhere on the board
Thermos_In_3: U4.33 (IO40); also elsewhere on the board
Thermos_In_4: U4.25 (IO48); also elsewhere on the board
Thermos_In_5: U4.14 (USB_D+); also elsewhere on the board
Thermos_In_6: U4.11 (IO18); also elsewhere on the board
Thermos_In_7: U4.9 (IO16); also elsewhere on the board
Thermos_Out_1: U4.39 (IO1); also elsewhere on the board
Thermos_Out_2: U4.34 (IO41); also elsewhere on the board
Thermos_Out_3: U4.32 (IO39); also elsewhere on the board
Thermos_Out_4: U4.24 (IO47); also elsewhere on the board
Thermos_Out_5: U4.13 (USB_D-); also elsewhere on the board
Thermos_Out_6: U4.10 (IO17); also elsewhere on the board
Thermos_Out_7: U4.8 (IO15); also elsewhere on the board
USB_D+: J18.A6 (D+), J18.B6 (D+), U1.5 (UD+)
USB_D-: J18.A7 (D-), J18.B7 (D-), U1.6 (UD-)
~INT: U3.36 (~INT), U4.22 (IO14)
~RST: U3.37 (~RST)
~SCS: U3.32 (~SCS), U4.18 (IO10)

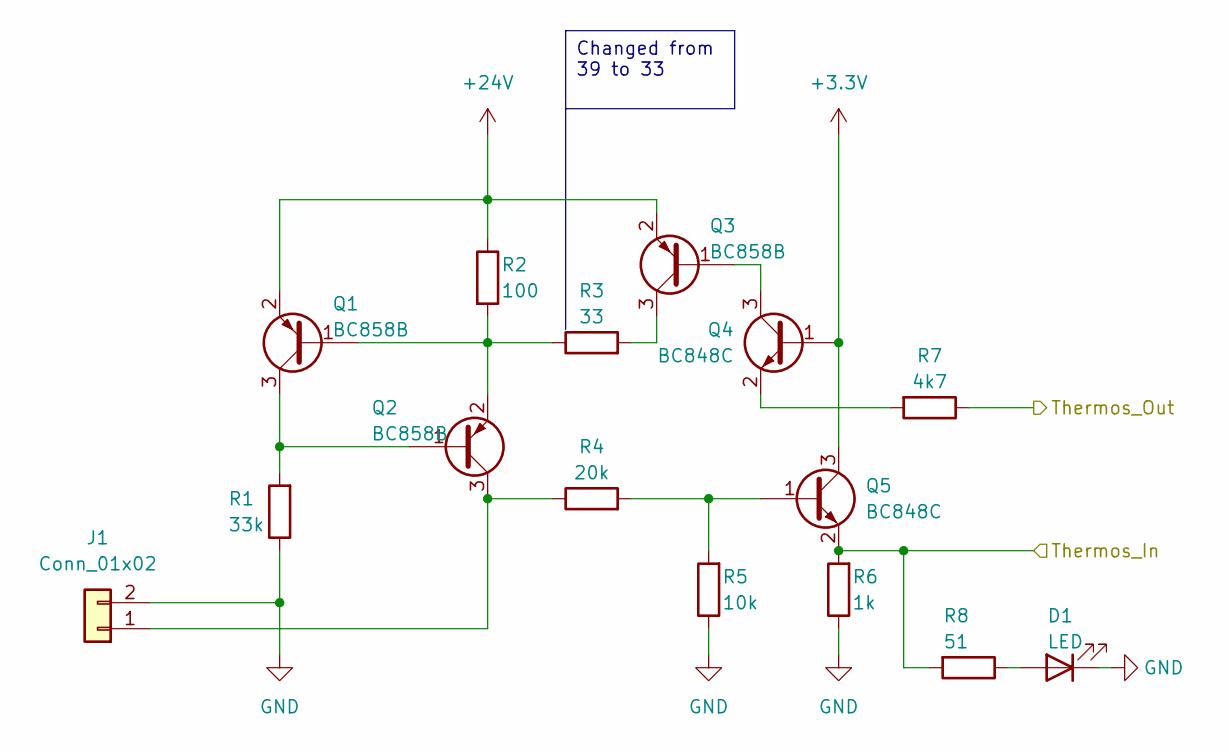
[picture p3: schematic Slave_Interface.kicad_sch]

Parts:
D1: LED; LED_0805_2012Metric
J1: Conn_01x02; PhoenixContact_MSTBA_2,5_2-G-5,08_1x02_P5.08mm_Horizontal
Q1, Q2, Q3: BC858B; SOT-23
Q4, Q5: BC848C; SOT-23
R1: 33k; R_0603_1608Metric
R2: 100; R_0603_1608Metric
R3: 33; R_0603_1608Metric
R4: 20k; R_0603_1608Metric
R5: 10k; R_0603_1608Metric
R6: 1k; R_0603_1608Metric
R7: 4k7; R_0603_1608Metric
R8: 51; R_0603_1608Metric

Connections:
+3.3V: Q4.1 (B), Q5.3 (C); also elsewhere on the board
+24V: Q1.2 (E), Q3.2 (E), R2.1; also elsewhere on the board
GND: D1.1 (K), J1.2, R1.1, R5.1, R6.1; also elsewhere on the board
unnamed: D1.2 (A), R8.1
unnamed: J1.1, Q2.3 (C), R4.1
unnamed: Q1.1 (B), Q2.2 (E), R2.2, R3.1
unnamed: Q1.3 (C), Q2.1 (B), R1.2
unnamed: Q3.1 (B), Q4.3 (C)
unnamed: Q3.3 (C), R3.2
unnamed: Q4.2 (E), R7.2
unnamed: Q5.1 (B), R4.2, R5.2
Thermos_In_1: Q5.2 (E), R6.2, R8.2; also elsewhere on the board
Thermos_Out_1: R7.1; also elsewhere on the board

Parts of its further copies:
D2, D3, D4, D5, D6, D7: LED; LED_0805_2012Metric
J2, J3, J4, J5, J6, J8: Conn_01x02; PhoenixContact_MSTBA_2,5_2-G-5,08_1x02_P5.08mm_Horizontal
Q6, Q7, Q8, Q11, Q12, Q13, Q16, Q17, Q18, Q21, Q22, Q23, Q26, Q27, Q28, Q39, Q40, Q41: BC858B; SOT-23
Q9, Q10, Q14, Q15, Q19, Q20, Q24, Q25, Q29, Q30, Q42, Q43: BC848C; SOT-23
R9, R16, R25, R33, R41, R68: 33k; R_0603_1608Metric
R10, R17, R26, R34, R42, R69: 100; R_0603_1608Metric
R11, R18, R27, R35, R43, R70: 33; R_0603_1608Metric
R12, R19, R28, R36, R44, R71: 20k; R_0603_1608Metric
R13, R20, R29, R37, R45, R72: 10k; R_0603_1608Metric
R14, R21, R30, R38, R46, R73: 1k; R_0603_1608Metric
R15, R22, R31, R39, R47, R74: 4k7; R_0603_1608Metric
R23, R24, R32, R40, R48, R75: 51; R_0603_1608Metric

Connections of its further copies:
+3.3V: Q9.1 (B), Q10.3 (C), Q14.1 (B), Q15.3 (C), Q19.1 (B), Q20.3 (C), Q24.1 (B), Q25.3 (C), Q29.1 (B), Q30.3 (C), Q42.1 (B), Q43.3 (C); also elsewhere on the board
+24V: Q6.2 (E), Q8.2 (E), Q11.2 (E), Q13.2 (E), Q16.2 (E), Q18.2 (E), Q21.2 (E), Q23.2 (E), Q26.2 (E), Q28.2 (E), Q39.2 (E), Q41.2 (E), R10.1, R17.1, R26.1, R34.1, R42.1, R69.1; also elsewhere on the board
GND: D2.1 (K), D3.1 (K), D4.1 (K), D5.1 (K), D6.1 (K), D7.1 (K), J2.2, J3.2, J4.2, J5.2, J6.2, J8.2, R9.1, R13.1, R14.1, R16.1, R20.1, R21.1, R25.1, R29.1, R30.1, R33.1, R37.1, R38.1, R41.1, R45.1, R46.1, R68.1, R72.1, R73.1; also elsewhere on the board
unnamed: D2.2 (A), R23.1
unnamed: D3.2 (A), R24.1
unnamed: D4.2 (A), R32.1
unnamed: D5.2 (A), R40.1
unnamed: D6.2 (A), R48.1
unnamed: D7.2 (A), R75.1
unnamed: J2.1, Q12.3 (C), R19.1
unnamed: J3.1, Q7.3 (C), R12.1
unnamed: J4.1, Q17.3 (C), R28.1
unnamed: J5.1, Q22.3 (C), R36.1
unnamed: J6.1, Q27.3 (C), R44.1
unnamed: J8.1, Q40.3 (C), R71.1
unnamed: Q6.1 (B), Q7.2 (E), R10.2, R11.1
unnamed: Q6.3 (C), Q7.1 (B), R9.2
unnamed: Q8.1 (B), Q9.3 (C)
unnamed: Q8.3 (C), R11.2
unnamed: Q9.2 (E), R15.2
unnamed: Q10.1 (B), R12.2, R13.2
unnamed: Q11.1 (B), Q12.2 (E), R17.2, R18.1
unnamed: Q11.3 (C), Q12.1 (B), R16.2
unnamed: Q13.1 (B), Q14.3 (C)
unnamed: Q13.3 (C), R18.2
unnamed: Q14.2 (E), R22.2
unnamed: Q15.1 (B), R19.2, R20.2
unnamed: Q16.1 (B), Q17.2 (E), R26.2, R27.1
unnamed: Q16.3 (C), Q17.1 (B), R25.2
unnamed: Q18.1 (B), Q19.3 (C)
unnamed: Q18.3 (C), R27.2
unnamed: Q19.2 (E), R31.2
unnamed: Q20.1 (B), R28.2, R29.2
unnamed: Q21.1 (B), Q22.2 (E), R34.2, R35.1
unnamed: Q21.3 (C), Q22.1 (B), R33.2
unnamed: Q23.1 (B), Q24.3 (C)
unnamed: Q23.3 (C), R35.2
unnamed: Q24.2 (E), R39.2
unnamed: Q25.1 (B), R36.2, R37.2
unnamed: Q26.1 (B), Q27.2 (E), R42.2, R43.1
unnamed: Q26.3 (C), Q27.1 (B), R41.2
unnamed: Q28.1 (B), Q29.3 (C)
unnamed: Q28.3 (C), R43.2
unnamed: Q29.2 (E), R47.2
unnamed: Q30.1 (B), R44.2, R45.2
unnamed: Q39.1 (B), Q40.2 (E), R69.2, R70.1
unnamed: Q39.3 (C), Q40.1 (B), R68.2
unnamed: Q41.1 (B), Q42.3 (C)
unnamed: Q41.3 (C), R70.2
unnamed: Q42.2 (E), R74.2
unnamed: Q43.1 (B), R71.2, R72.2
Thermos_In_2: Q15.2 (E), R21.2, R23.2; also elsewhere on the board
Thermos_In_3: Q10.2 (E), R14.2, R24.2; also elsewhere on the board
Thermos_In_4: Q20.2 (E), R30.2, R32.2; also elsewhere on the board
Thermos_In_5: Q25.2 (E), R38.2, R40.2; also elsewhere on the board
Thermos_In_6: Q30.2 (E), R46.2, R48.2; also elsewhere on the board
Thermos_In_7: Q43.2 (E), R73.2, R75.2; also elsewhere on the board
Thermos_Out_2: R22.1; also elsewhere on the board
Thermos_Out_3: R15.1; also elsewhere on the board
Thermos_Out_4: R31.1; also elsewhere on the board
Thermos_Out_5: R39.1; also elsewhere on the board
Thermos_Out_6: R47.1; also elsewhere on the board
Thermos_Out_7: R74.1; also elsewhere on the board

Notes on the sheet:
Changed from 39 to 33

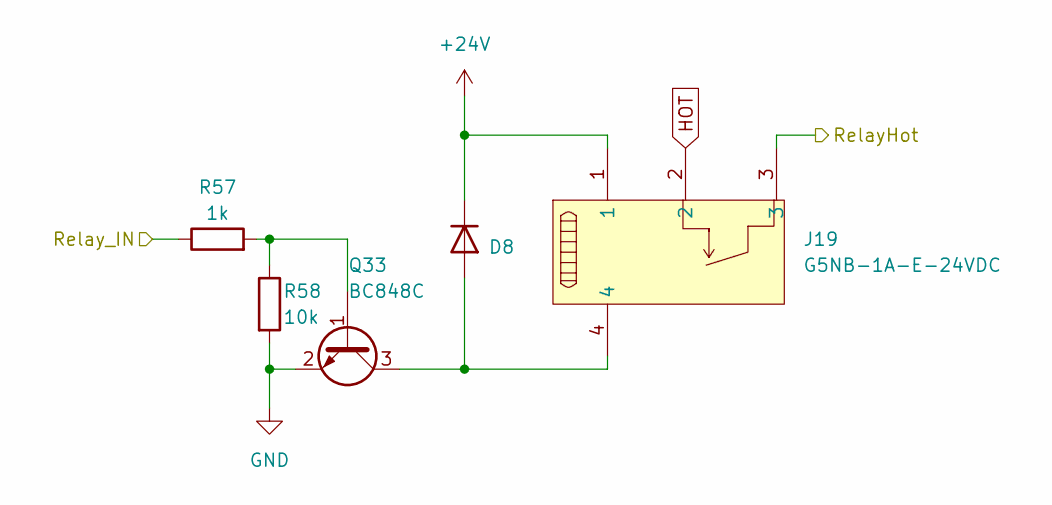
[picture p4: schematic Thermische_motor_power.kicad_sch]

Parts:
D8: 1N4148WS; D_SOD-323
J19: G5NB-1A-E-24VDC; RELAY-TH_G5NB-1A-E-24VDC; MPN G5NB-1A-E-24VDC; LCSC Part C34758
Q33: BC848C; SOT-23
R57: 1k; R_0603_1608Metric
R58: 10k; R_0603_1608Metric

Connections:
+24V: D8.1 (K), J19.1; also elsewhere on the board
/thermische motor 1/RelayHot: J19.3; also elsewhere on the board
/thermische motor 1/Relay_IN: R57.1; also elsewhere on the board
GND: Q33.2 (E), R58.2; also elsewhere on the board
HOT: J19.2; also elsewhere on the board
unnamed: D8.2 (A), J19.4, Q33.3 (C)
unnamed: Q33.1 (B), R57.2, R58.1

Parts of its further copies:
D9, D18, D19, D20, D21, D22: 1N4148WS; D_SOD-323
J20, J21, J22, J23, J25, J26: G5NB-1A-E-24VDC; RELAY-TH_G5NB-1A-E-24VDC; MPN G5NB-1A-E-24VDC; LCSC Part C34758
Q31, Q34, Q35, Q36, Q37, Q38: BC848C; SOT-23
R49, R51, R60, R62, R64, R66: 1k; R_0603_1608Metric
R50, R59, R61, R63, R65, R67: 10k; R_0603_1608Metric

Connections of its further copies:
+24V: D9.1 (K), D18.1 (K), D19.1 (K), D20.1 (K), D21.1 (K), D22.1 (K), J20.1, J21.1, J22.1, J23.1, J25.1, J26.1; also elsewhere on the board
/thermische motor 2/RelayHot: J20.3; also elsewhere on the board
/thermische motor 2/Relay_IN: R49.1; also elsewhere on the board
/thermische motor 3/RelayHot: J21.3; also elsewhere on the board
/thermische motor 3/Relay_IN: R51.1; also elsewhere on the board
/thermische motor 4/RelayHot: J22.3; also elsewhere on the board
/thermische motor 4/Relay_IN: R60.1; also elsewhere on the board
/thermische motor 5/RelayHot: J23.3; also elsewhere on the board
/thermische motor 5/Relay_IN: R62.1; also elsewhere on the board
/thermische motor 6/RelayHot: J25.3; also elsewhere on the board
/thermische motor 6/Relay_IN: R64.1; also elsewhere on the board
/thermische motor 7/RelayHot: J26.3; also elsewhere on the board
/thermische motor 7/Relay_IN: R66.1; also elsewhere on the board
GND: Q31.2 (E), Q34.2 (E), Q35.2 (E), Q36.2 (E), Q37.2 (E), Q38.2 (E), R50.2, R59.2, R61.2, R63.2, R65.2, R67.2; also elsewhere on the board
HOT: J20.2, J21.2, J22.2, J23.2, J25.2, J26.2; also elsewhere on the board
unnamed: D9.2 (A), J20.4, Q31.3 (C)
unnamed: D18.2 (A), J21.4, Q34.3 (C)
unnamed: D19.2 (A), J22.4, Q35.3 (C)
unnamed: D20.2 (A), J23.4, Q36.3 (C)
unnamed: D21.2 (A), J25.4, Q37.3 (C)
unnamed: D22.2 (A), J26.4, Q38.3 (C)
unnamed: Q31.1 (B), R49.2, R50.1
unnamed: Q34.1 (B), R51.2, R59.1
unnamed: Q35.1 (B), R60.2, R61.1
unnamed: Q36.1 (B), R62.2, R63.1
unnamed: Q37.1 (B), R64.2, R65.1
unnamed: Q38.1 (B), R66.2, R67.1

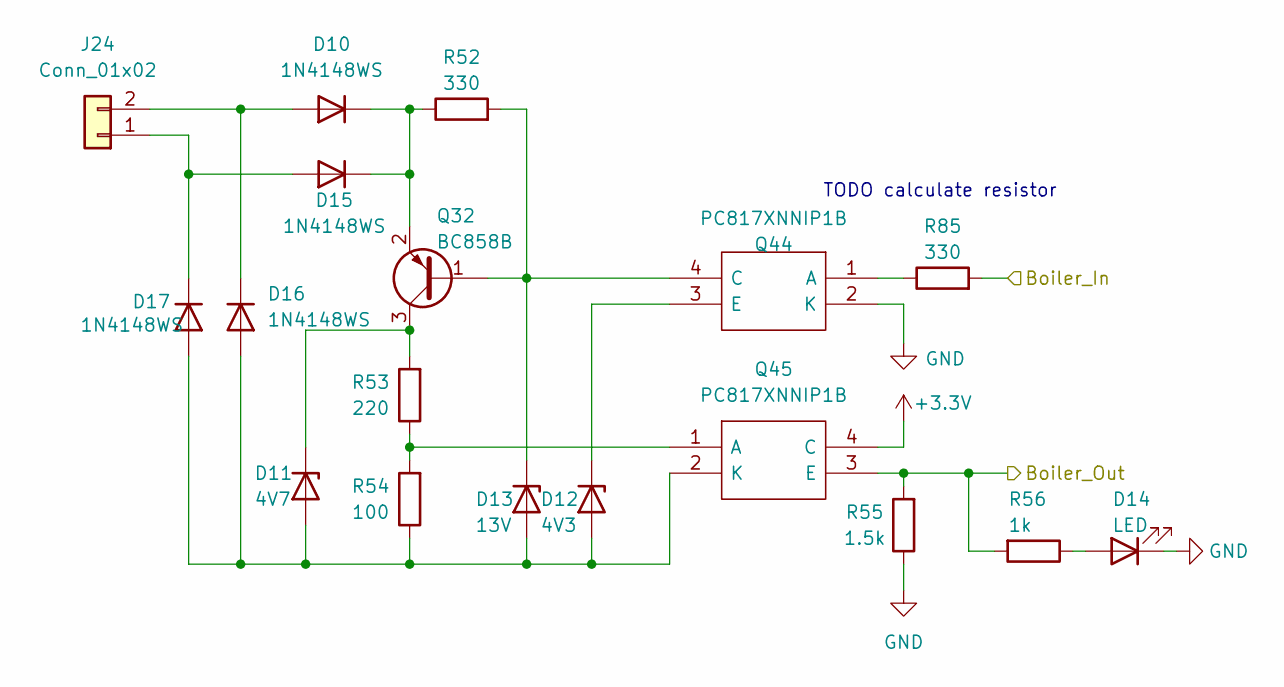
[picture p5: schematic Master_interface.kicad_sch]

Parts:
D10, D15, D16, D17: 1N4148WS; D_SOD-323
D11: 4V7; D_SOD-323_HandSoldering
D12: 4V3; D_SOD-323_HandSoldering
D13: 13V; D_SOD-323_HandSoldering
D14: LED; LED_0805_2012Metric
J24: Conn_01x02; PhoenixContact_MSTBA_2,5_2-G-5,08_1x02_P5.08mm_Horizontal
Q32: BC858B; SOT-23
Q44, Q45: PC817XNNIP1B; SOP254P960X420-4N; Manufacturer_Part_Number PC817XNNIP1B; Mouser Part Number 852-PC817XNNIP1B
R52, R85: 330; R_0603_1608Metric
R53: 220; R_0603_1608Metric
R54: 100; R_0603_1608Metric
R55: 1.5k; R_0603_1608Metric
R56: 1k; R_0603_1608Metric

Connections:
+3.3V: Q45.4 (C); also elsewhere on the board
Boiler_In: R85.2; also elsewhere on the board
Boiler_Out: Q45.3 (E), R55.2, R56.2; also elsewhere on the board
GND: D14.1 (K), Q44.2 (K), R55.1; also elsewhere on the board
unnamed: D10.2 (A), D16.1 (K), J24.2
unnamed: D10.1 (K), D15.1 (K), Q32.2 (E), R52.1
unnamed: D11.2 (A), D12.2 (A), D13.2 (A), D16.2 (A), D17.2 (A), Q45.2 (K), R54.1
unnamed: D11.1 (K), Q32.3 (C), R53.2
unnamed: D12.1 (K), Q44.3 (E)
unnamed: D13.1 (K), Q32.1 (B), Q44.4 (C), R52.2
unnamed: D14.2 (A), R56.1
unnamed: D15.2 (A), D17.1 (K), J24.1
unnamed: Q44.1 (A), R85.1
unnamed: Q45.1 (A), R53.1, R54.2

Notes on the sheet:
TODO calculate resistor

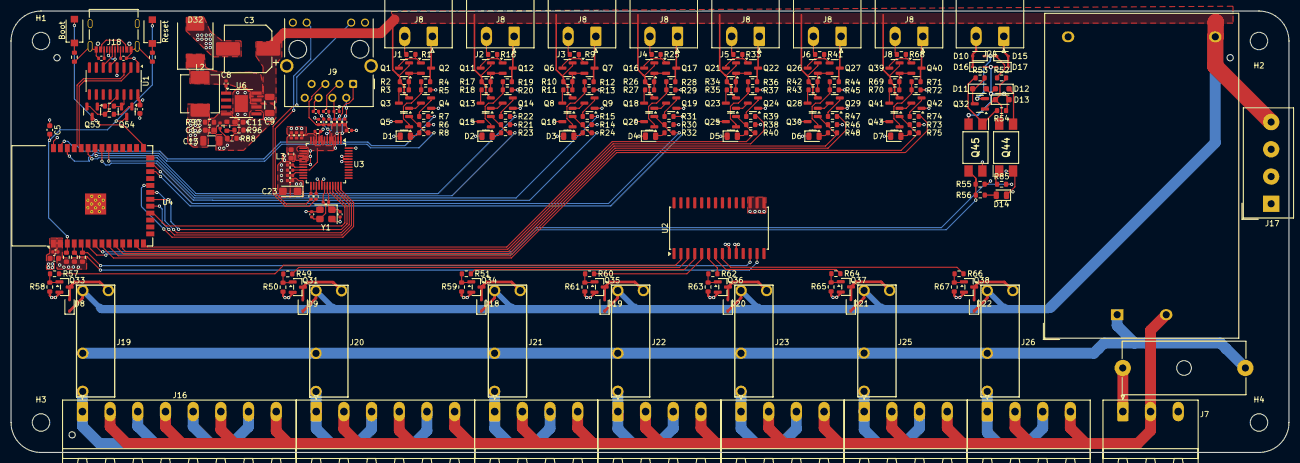
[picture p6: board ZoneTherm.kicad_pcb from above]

Board: 4 copper layers, 234.5 x 81.0 mm, 236 parts (0 on the bottom side), 161 nets.

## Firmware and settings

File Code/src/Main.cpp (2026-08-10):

// Composition root: builds the object graph and runs the control loop.
// No singletons - everything below receives its dependencies explicitly.

#include "driver/gpio.h"
#include "esp_log.h"
#include "esp_timer.h"
#include "freertos/FreeRTOS.h"
#include "freertos/task.h"
#include "nvs_flash.h"

#include "app/Pins.h"
#include "app/Version.h"
#include "domain/ClimateLogic.h"
#include "domain/ValvePlan.h"
#include "domain/ZoneRegistry.h"
#include "drivers/ValveBank.h"
#include "net/MdnsService.h"
#include "net/NetworkManager.h"
#include "services/ConfigStore.h"
#include "services/ControlService.h"
#include "services/MqttService.h"
#include "services/OtEngine.h"
#include "services/TimeService.h"
#include "services/UpdateService.h"
#include "web/HttpServer.h"
#include "web/OtaRoutes.h"

namespace {

const char* TAG = "Main";

void logZoneStatus(ZoneRegistry& zones, ControlService& control,
                   const AppConfig& cfg) {
    const uint8_t openValves = control.openValveMask();
    for (int i = 0; i < kNumZones; i++) {
        const ZoneSnapshot z = zones.snapshot(i);
        const bool valveOpen =
            ValvePlan::anyOpen(cfg.zones[i].valveMask, openValves);
        ESP_LOGI(TAG,
                 "Zone %d (%s): %.1f/%.1f degC %s valves=0x%02X %s req=%lu fail=%lu",
                 i + 1, cfg.zones[i].name.c_str(), z.roomTemp, z.setpoint,
                 ClimateLogic::actionString(cfg.zones[i].enabled,
                                            cfg.control.mode, valveOpen),
                 cfg.zones[i].valveMask, valveOpen ? "open" : "closed",
                 static_cast<unsigned long>(z.totalRequests),
                 static_cast<unsigned long>(z.failedRequests));
    }
}

}  // namespace

extern "C" void app_main() {
    esp_err_t nvsErr = nvs_flash_init();
    if (nvsErr == ESP_ERR_NVS_NO_FREE_PAGES || nvsErr == ESP_ERR_NVS_NEW_VERSION_FOUND) {
        nvs_flash_erase();
        nvs_flash_init();
    }

    ESP_LOGI(TAG, "ZoneTherm controller %s starting", FW_VERSION);

    // Installed once, up front: OtEngine's task (OpenTherm bit-banging) and
    // the W5500 Ethernet driver both need the shared per-pin GPIO ISR
    // service, and each assumes it's already there rather than installing
    // it themselves. Left to chance, otEngine.start() below hands its task
    // to core 1 asynchronously, so whichever of that task or
    // network.begin() (running here on the main task) happens to reach its
    // gpio_isr_handler_add() first would win a boot-order race; the loser's
    // interrupt silently never gets registered (the W5500 driver in
    // particular doesn't check the call's return value).
    esp_err_t isrErr = gpio_install_isr_service(0);
    if (isrErr != ESP_OK && isrErr != ESP_ERR_INVALID_STATE) {
        ESP_LOGE(TAG, "gpio_install_isr_service failed: %s", esp_err_to_name(isrErr));
    }

    static ConfigStore config;
    config.load();

    static ZoneRegistry zones;

    static ValveBank valves;
    valves.begin(pins::kI2cSda, pins::kI2cScl);

    static OtEngine otEngine(zones, config);
    otEngine.start();

    static ControlService control(zones, valves, config);

    static NetworkManager network(config);
    network.begin();
    TimeService::begin();
    MdnsService::begin(config.get().net.hostname);

    static MqttService mqtt(zones, config, control);
    mqtt.begin();

    static UpdateService updates(config, otEngine, control);
    updates.setFlashBusyProbe(manualOtaActive);
    updates.begin();

    static WebContext webContext{zones,     config,  network, control,
                                 otEngine,  updates, [] { mqtt.restart(); }};
    static HttpServer httpServer(webContext);
    httpServer.start();

    int64_t lastStatusLog = 0;
    for (;;) {
        network.tick();
        control.tick();
        mqtt.tick();
        updates.tick(network.isConnected());

        // Periodic serial diagnostic
        const int64_t now = esp_timer_get_time();
        if (now - lastStatusLog > 30LL * 1000 * 1000) {
            lastStatusLog = now;
            logZoneStatus(zones, control, config.get());
        }

        vTaskDelay(pdMS_TO_TICKS(1000));
    }
}

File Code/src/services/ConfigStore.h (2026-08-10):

// Runtime configuration: typed struct, NVS persistence, defaults and
// one-time migration from the legacy `opentherm` namespace. Replaces the
// compile-time constants (including credentials) that used to live in
// SystemConfig.cpp.

#pragma once

#include <cstdint>
#include <functional>
#include <mutex>
#include <string>

#include "../domain/ZoneState.h"

struct NetworkConfig {
    std::string wifiSsid;   // empty = no WiFi configured -> SoftAP fallback
    std::string wifiPass;
    std::string hostname;   // default "zonetherm-<ID>"
};

struct MqttConfig {
    bool enabled = false;   // stays off until a broker host is set
    std::string host;
    uint16_t port = 1883;
    std::string user;
    std::string pass;
    std::string baseTopic;        // default "zonetherm/<ID>"
    std::string discoveryPrefix;  // default "homeassistant"
};

struct ZoneConfig {
    std::string name;       // default "Thermostat <n>"
    bool enabled = true;

    // Valve outputs this thermostat drives; bit v = valve v, V1 = bit 0. A
    // thermostat may drive several (a room with three underfloor loops) and a
    // valve belongs to at most one thermostat. 0 means the thermostat still
    // answers and still tracks its band, but opens nothing - a deliberately
    // fail-safe struct default. applyDefaults() installs the legacy 1:1
    // mapping (zone i -> valve i).
    uint8_t valveMask = 0;
};

struct ControlConfig {
    Season mode = Season::Heating;
    uint16_t hysteresisCentiK = 30;  // 0.30 K band

    float hysteresisK() const { return hysteresisCentiK / 100.0f; }
};

struct UpdateConfig {
    bool enabled = true;             // periodic GitHub release checks
    bool autoInstall = false;        // false = notify only, wait for a click
    std::string repo;                // "owner/name"; default kDefaultRepo
    uint16_t checkIntervalH = 24;
    bool includeFilesystem = true;   // also pull littlefs.bin (the web UI)
};

struct AppConfig {
    NetworkConfig net;
    MqttConfig mqtt;
    ZoneConfig zones[kNumZones];
    ControlConfig control;
    UpdateConfig update;

    // Derived from the MAC at boot, never persisted.
    std::string controllerId;
};

class ConfigStore {
public:
    // Reads NVS (namespace "otcfg"); on first boot imports the legacy
    // "opentherm" namespace (sysmode + thermostat names). Requires
    // nvs_flash_init() to have run.
    void load();

    AppConfig get() const;

    // Runs the mutator under the lock, then persists everything to NVS.
    // NVS skips writes for unchanged values, so saving all keys is cheap.
    void mutate(const std::function<void(AppConfig&)>& fn);

    // Erases the otcfg namespace and reverts the in-memory config to
    // defaults. Caller is expected to reboot shortly after.
    void factoryReset();

private:
    void applyDefaults();
    void migrateLegacy();
    void readNvs();
    void writeNvs() const;

    mutable std::mutex mutex_;
    AppConfig cfg_;
};

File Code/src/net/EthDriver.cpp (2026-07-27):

#include "EthDriver.h"

#include <cstdio>

#include "esp_log.h"

namespace {
const char* TAG = "EthDriver";
}

#include "driver/spi_master.h"
#include "esp_eth.h"
#include "esp_eth_mac_spi.h"
#include "esp_mac.h"

namespace {

// W5500 SPI nets on the ZoneTherm PCB (see U3 on ZoneTherm.kicad_pcb).
constexpr int kPhyCs = 10;
constexpr int kPhyIrq = 14;
constexpr int kPhyRst = -1;
constexpr int kSpiSck = 12;
constexpr int kSpiMiso = 13;
constexpr int kSpiMosi = 11;
// Default is 20MHz; dropped while debugging link flapping in case the
// wiring can't reliably hold the full speed.
constexpr int kSpiFreqMhz = 20;
constexpr auto kSpiHost = SPI2_HOST;

}  // namespace

void EthDriver::onEthEvent(void* arg, esp_event_base_t, int32_t id, void* data) {
    auto* self = static_cast<EthDriver*>(arg);
    switch (id) {
        case ETHERNET_EVENT_CONNECTED: {
            esp_eth_handle_t handle = *static_cast<esp_eth_handle_t*>(data);
            esp_eth_ioctl(handle, ETH_CMD_G_MAC_ADDR, self->mac_);
            ESP_LOGI(TAG, "link up");
            break;
        }
        case ETHERNET_EVENT_DISCONNECTED:
        case ETHERNET_EVENT_STOP:
            self->gotIp_ = false;
            ESP_LOGI(TAG, "link down");
            break;
        default:
            break;
    }
}

void EthDriver::onIpEvent(void* arg, esp_event_base_t, int32_t id, void* data) {
    auto* self = static_cast<EthDriver*>(arg);
    if (id == IP_EVENT_ETH_GOT_IP) {
        auto* event = static_cast<ip_event_got_ip_t*>(data);
        self->ipInfo_ = event->ip_info;
        self->gotIp_ = true;
        char buf[16];
        esp_ip4addr_ntoa(&self->ipInfo_.ip, buf, sizeof(buf));
        ESP_LOGI(TAG, "got IP %s", buf);
    } else if (id == IP_EVENT_ETH_LOST_IP) {
        self->gotIp_ = false;
        ESP_LOGI(TAG, "lost IP");
    }
}

void EthDriver::begin() {
    spi_bus_config_t busConfig = {};
    busConfig.mosi_io_num = kSpiMosi;
    busConfig.miso_io_num = kSpiMiso;
    busConfig.sclk_io_num = kSpiSck;
    busConfig.quadwp_io_num = -1;
    busConfig.quadhd_io_num = -1;
    esp_err_t err = spi_bus_initialize(kSpiHost, &busConfig, SPI_DMA_CH_AUTO);
    if (err != ESP_OK && err != ESP_ERR_INVALID_STATE) {
        ESP_LOGE(TAG, "spi_bus_initialize failed: %s", esp_err_to_name(err));
        return;
    }

    spi_device_interface_config_t spiDeviceConfig = {};
    spiDeviceConfig.mode = 0;
    spiDeviceConfig.clock_speed_hz = kSpiFreqMhz * 1000 * 1000;
    spiDeviceConfig.queue_size = 20;
    spiDeviceConfig.spics_io_num = kPhyCs;

    eth_w5500_config_t w5500Config = ETH_W5500_DEFAULT_CONFIG(kSpiHost, &spiDeviceConfig);
    w5500Config.int_gpio_num = kPhyIrq;

    eth_mac_config_t macConfig = ETH_MAC_DEFAULT_CONFIG();
    esp_eth_mac_t* mac = esp_eth_mac_new_w5500(&w5500Config, &macConfig);

    eth_phy_config_t phyConfig = ETH_PHY_DEFAULT_CONFIG();
    phyConfig.phy_addr = 0;
    phyConfig.reset_gpio_num = kPhyRst;
    esp_eth_phy_t* phy = esp_eth_phy_new_w5500(&phyConfig);

    esp_eth_config_t ethConfig = ETH_DEFAULT_CONFIG(mac, phy);
    esp_eth_handle_t ethHandle = nullptr;
    err = esp_eth_driver_install(&ethConfig, &ethHandle);
    if (err != ESP_OK) {
        ESP_LOGE(TAG, "driver install FAILED - check SPI wiring/CS/IRQ pins and W5500 power: %s",
                 esp_err_to_name(err));
        return;
    }

    // The W5500 has no factory-burned MAC (unlike the ESP32's internal EMAC),
    // and neither esp_eth_driver_install nor the W5500 driver programs one -
    // the chip comes up with an all-zero SHAR. Left as-is the link comes up
    // but every DHCP DISCOVER goes out with source MAC 00:00:00:00:00:00,
    // which routers/switches drop, so DHCP never completes. Derive a stable
    // per-chip MAC from the ESP32 efuse base MAC and program it, exactly as
    // the ESP-IDF SPI-Ethernet examples do (Arduino's Ethernet.begin(mac,...)
    // used to force this on us; the IDF port had dropped it).
    uint8_t macAddr[6];
    esp_read_mac(macAddr, ESP_MAC_ETH);
    err = esp_eth_ioctl(ethHandle, ETH_CMD_S_MAC_ADDR, macAddr);
    if (err != ESP_OK) {
        ESP_LOGE(TAG, "set MAC FAILED: %s", esp_err_to_name(err));
    } else {
        ESP_LOGI(TAG, "MAC set to %02X:%02X:%02X:%02X:%02X:%02X",
                 macAddr[0], macAddr[1], macAddr[2], macAddr[3], macAddr[4], macAddr[5]);
    }

    esp_netif_config_t netifConfig = ESP_NETIF_DEFAULT_ETH();
    esp_netif_t* netif = esp_netif_new(&netifConfig);
    esp_netif_attach(netif, esp_eth_new_netif_glue(ethHandle));

    esp_event_handler_instance_register(ETH_EVENT, ESP_EVENT_ANY_ID,
                                        &EthDriver::onEthEvent, this, nullptr);
    esp_event_handler_instance_register(IP_EVENT, IP_EVENT_ETH_GOT_IP,
                                        &EthDriver::onIpEvent, this, nullptr);
    esp_event_handler_instance_register(IP_EVENT, IP_EVENT_ETH_LOST_IP,
                                        &EthDriver::onIpEvent, this, nullptr);

    err = esp_eth_start(ethHandle);
    if (err == ESP_OK) {
        ESP_LOGI(TAG, "started, waiting for link/DHCP");
    } else {
        ESP_LOGE(TAG, "esp_eth_start FAILED: %s", esp_err_to_name(err));
    }
}

std::string EthDriver::ip() const {
    char buf[16] = {0};
    esp_ip4addr_ntoa(&ipInfo_.ip, buf, sizeof(buf));
    return buf;
}

std::string EthDriver::mac() const {
    char buf[18];
    std::snprintf(buf, sizeof(buf), "%02X:%02X:%02X:%02X:%02X:%02X",
                  mac_[0], mac_[1], mac_[2], mac_[3], mac_[4], mac_[5]);
    return buf;
}

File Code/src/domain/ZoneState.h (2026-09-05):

// Plain zone state shared between the OT engine, control loop, MQTT and web.
// No IDF/FreeRTOS dependencies - host-compilable.

#pragma once

#include <cstdint>

constexpr int kNumZones = 7;   // thermostat channels (OpenTherm slave ports)
constexpr int kNumValves = 7;  // valve outputs V1..V7 on the MCP23017 port B

// A thermostat drives a set of valves, carried as a bitmask with V1 = bit 0.
// The two counts are independent on purpose: they are equal on this board, but
// nothing below couples a thermostat index to a valve index any more.
static_assert(kNumValves <= 8, "valve sets are carried in a uint8_t");
constexpr uint8_t kAllValvesMask = static_cast<uint8_t>((1u << kNumValves) - 1);

// Global season: one heating/cooling plant, all zones follow it.
enum class Season : uint8_t {
    Heating = 0,
    Cooling = 1,
};

struct ZoneState {
    // Climate values captured from / pushed to the room thermostat
    float setpoint = 20.0f;         // last room setpoint the thermostat sent (TrSet)
    float overrideSetpoint = 0.0f;  // pending TrOverride push; 0 = no override
    float roomTemp = 0.0f;          // 0 = thermostat has not reported yet
    float boilerTemp = 0.0f;
    float modulation = 0.0f;
    float coolingControl = 0.0f;

    bool flameOn = false;
    bool fault = false;
    uint8_t errorCode = 0;

    // Diagnostics
    uint32_t totalRequests = 0;
    uint32_t failedRequests = 0;
    uint32_t lastRequestMs = 0;  // 0 = never seen a request
};

// Value copy handed out by ZoneRegistry; safe to read without holding any lock.
using ZoneSnapshot = ZoneState;

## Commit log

2026-07-27 ZoneTherm 1.0.0
    [BOM-OpenTherm.csv, Master_interface.kicad_sch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]
2026-07-27 Pin espressif32 platform to the pioarduino ESP-IDF 5.5.4 release
    The bare `platform = espressif32` resolved to whatever was already
    installed locally (pioarduino 55.3.39, ESP-IDF 5.5.4) but to the latest
    platformio/espressif32 7.x in CI, which ships ESP-IDF 6.0.1. IDF 6.0 no
    longer bundles esp-mqtt, so components/mqtt is an unpopulated submodule
    directory and the `mqtt` entry in src/CMakeLists.txt REQUIRES fails to
    resolve, breaking the release build at CMake configure time.
    Pinning the platform URL makes CI build the same toolchain the firmware
    is developed and flash-tested against, matching dependencies.lock.
2026-07-27 ZoneTherm 1.0.1: read the release redirect Location correctly
    esp_http_client_get_header() looks up *request* headers, so asking it for
    "Location" always returned NULL and every update check failed with
    "redirect without a Location header" - the check could never succeed.
    Capture the header through HTTP_EVENT_ON_HEADER instead, which is the only
    public route to a response header. IDF dispatches that event once per
    fully-assembled header line, so a plain assignment is enough.
2026-07-27 ZoneTherm 1.0.2: fix asset downloads and the empty filesystem image
    Three defects, all on the path a release actually travels:
    - GitHub redirects asset downloads to a signed githubusercontent.com URL
    ~900 bytes long. esp_http_client formats the request line into its TX
    buffer and bails with "Out of buffer" past 512 bytes, so the firmware
    download always failed with ESP_FAIL. Raise both buffers to 2048.
    - installFilesystem() used the open/read path, which never follows
    redirects (esp_http_client only does that inside perform()), so it would
    have failed with "HTTP 302" the moment a firmware update got far enough
    to invoke it. Follow the redirect chain by hand.
    - webui_build.py h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
2026-08-10 Add host unit tests for the domain layer, and CI
    src/domain/ is the part of the firmware with no ESP-IDF includes, which
    makes it the tested boundary: the frame codec, the request responder, the
    zone registry and the valve decision all compile and run off-device.
    Five Unity suites under test/, plus an env:native that builds them with
    build_src_filter = +<domain/> so nothing drags in the IDF. The device env
    gets test_ignore = * to stop the suites' main() definitions colliding with
    the firmware.
    CI runs two independent jobs on every push and PR: the host tests, which
    need no toolchain download and take seconds, and a full firmware plus
    filesystem build so a compile break surfaces here rather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
2026-08-10 Let one thermostat drive a set of valves
    The thermostat->valve mapping was hard-wired 1:1 by array index: the
    coupling was literally the loop variable in ControlService::tick() and a
    bit shift in ValveBank. A room with three underfloor loops therefore
    needed three thermostats and three OpenTherm channels.
    Each zone now carries a valveMask, picked with checkboxes on the config
    page. ValvePlan::solve() runs the per-room decision (ClimateLogic is
    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
2026-08-10 Fix env:native linking no project sources into tests
    `pio test -e native` errored on four of six suites with "undefined
    reference" at link time. build_src_filter chooses WHICH sources a target
    builds, but a test target links only its own test/ sources unless
    test_build_src is enabled - so src/domain/*.cpp was never compiled in.
    The failure looked selective rather than total, which hid it: OtFrame and
    StringUtils are header-only, so their two suites passed either way, while
    ClimateLogic, ValvePlan, OtResponder and ZoneRegistry all failed.
    This was never caught because the harness had not run to completion
    anywhere. It cannot run on the Windows dev box (no g++), and ci.yml was
    still uncommit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
2026-09-05 Remove the per-zone outside temperature
    Nothing consumed it: the web UI never read outsideTemp, and the value
    only ever came from whatever a room thermostat chose to write to ID 27.
    Drop the ZoneState field, the responder's Toutside case (the ID now gets
    the standard UnknownDataId reply), the MQTT/HA sensor, the JSON field,
    and the tests and docs that mentioned it.
    Claude-Session: https://claude.ai/code/session_013cufjDt2x4oKMoLqvr7jRp
2026-09-11 Pin PlatformIO to 6.1.19 in CI
    The firmware build started failing on 2026-09-05 with
    *** [firmware.elf] ModuleNotFoundError : No module named 'SCons.Tool.FortranCommon'
    on a commit that only removed outside-temperature code. Nothing in the
    project changed: PlatformIO 6.2.0 was released that same day, and CI
    installs it with `pip install --upgrade platformio`.
    6.2.0 raises its tool-scons requirement from 4.40801.0 (SCons 4.8.1) to
    4.41101.0 and no longer leaves SCons in the tool-scons package directory
    at all, while the pioarduino platform pinned in platformio.ini still
    expects SCons 4.8.1 to live there. Linking firmware.elf then imports a
    module that is not on the path any more.
    Reprod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
